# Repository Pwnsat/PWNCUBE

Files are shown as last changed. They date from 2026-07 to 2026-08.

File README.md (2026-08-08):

# PWNCUBE - The Vulnerable Satellite Hacking Platform for Learning Through Research

**A hardware-based CubeSat platform for aerospace cybersecurity research and training**, developed by PWNSAT in partnership with [ElectronicCats](https://github.com/ElectronicCats). PWNCUBE is a satellite design and vulnerability set onto real dual-core flight-computer hardware (Rockchip RV1106 — Cortex-A7 Linux + RISC-V RT-Thread), demonstrating that the same class of satellite command-and-control vulnerabilities reproduces across genuinely different hardware, not just one reference board.

Full documentation, architecture diagrams, and step-by-step guides live in the **[Wiki](../../wiki)**.

## Repository layout

| Folder | Contents |
|---|---|
| [`Firmware/`](Firmware/) | The complete RV1106 SDK source: dual-core boot (Cortex-A7 Linux + RISC-V RT-Thread), CCSDS Space Packet Protocol stack, radio/sensor/GPS drivers, build scripts. Clone-and-build (see [Getting Started](../../wiki/Getting-Started)). |
| [`Hardware/`](Hardware/) | KiCad schematics and PCB design files for the three physical boards (main/flight-computer, sensor, battery). |
| [`Case/`](Case/) | 3D-printable enclosure (STL + slicer project files). |

The 8 hardware-validated attack scripts (00–07, USB and real RF) live in a
companion `Attacks/` repository, published separately.

## What PWNCUBE demonstrates

Same protocol (CCSDS Space Packet Protocol), same command APIDs, same vulnerability classes as FlatSat — reproduced on real dual-core flight hardware instead of a single-MCU reference board:

- **No authentication** on any telecommand (thruster control, reset, firmware disclosure, mode changes)
- **No anti-replay protection** — a captured command can be resent verbatim and re-executed
- **A ground-station "auth" handshake** trivially forgeable with a static, hardcoded XOR key
- **A GPS subsystem** (real u-blox NEO-6M receiver) that trusts any injected fix with zero plausibility or rate-of-change checking
- **Plaintext telemetry by default** — no encryption on the downlink at all, unlike FlatSat's static-key AES-128
- **A memory-safety bug** (integer underflow in message reassembly) that crashes the flight computer's real-time core with a single malformed packet, permanently killing the internal command channel until a physical power-cycle

See the **[Attack Vectors](../../wiki/Attack-Vectors)** wiki page for the full walkthrough of all 8 attacks, with real hardware output for each.

## Quick start

```bash
git clone <this-repo-url> PWNCUBE-FIRMWARE
cd PWNCUBE-FIRMWARE/Firmware
# extract toolchain.tar.gz + rkbin.tar.gz from the v6 Release first — see below
./build.sh deps      # install host build dependencies (native Linux x86-64)
./build.sh            # produces output/images/update.img
```

On macOS, Windows, or if you'd rather not install packages on the host
directly, build inside Docker instead — see **[Getting Started](../../wiki/Getting-Started)**
for the full walkthrough (both paths), including flashing, which always
needs a real Linux x86-64 host or VM with USB passthrough regardless of how
you built.

## Note on repository size

This repository intentionally excludes two things present in the original SDK archive, both available as assets on the **[v6 Release](../../releases/tag/v6)**:

- **`toolchain/`** (ARM + RISC-V cross-compilers, ~2.6GB) — third-party, freely redistributable, just too large for a source repo.
- **`src/rkbin/`** (Rockchip's proprietary boot-stage binaries) — third-party, provided by ElectronicCats.

Everything else — kernel, U-Boot, the RT-Thread MCU firmware, all PWNSAT-authored application code — is included as source.

## Disclaimer

This project was created for educational purposes, to teach and learn aerospace cybersecurity. Neither PWNSAT nor Electronic Cats are responsible for how the knowledge, code, or tools hosted in this repository are used. Use only against hardware, firmware, or signal sources you own or are explicitly authorized to test.

## License

Firmware source: see [`Firmware/README.md`](Firmware/README.md#license) for the per-component breakdown (this SDK integrates code under several different open-source licenses). Attack scripts and this repository's own documentation: MIT unless noted otherwise.

## Related projects

- **[FlatSat](https://github.com/Pwnsat/FlatSat)** — the original single-MCU (RP2040) satellite security training platform this project ports from.
- **PWNSAT-C3** — the shared ground-station dashboard used to operate both FlatSat and PWNCUBE (separate repository).

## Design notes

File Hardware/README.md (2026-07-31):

# PWNCUBE hardware — KiCad schematics and PCB design files

Design files for the three physical boards that make up a PWNCUBE (see
[Hardware Anatomy](https://github.com/Pwnsat/PWNCUBE/wiki/Hardware-Anatomy)
in the wiki for how they connect and what runs on each).

| Folder | Board | Contains |
|---|---|---|
| `PWNSAT/` | Main / flight-computer board | RV1106 SoC, radios, USB selector, power supply |
| `Sensor_Board/` | Sensor board | BME280 + ICM-42670, sensor connectors |
| `Battery_Board/` | Power/battery board | Battery holder, USB, battery connector |

Each board folder is a self-contained KiCad project: `.kicad_pro` (project),
`.kicad_sch` (schematic sheets), `.kicad_pcb` (PCB layout), `.pretty/`
(custom footprint library), and `3D/` (3D models for parts used in that
board's layout, `.step`/`.stp`/`.igs`).

## Opening a project

Requires [KiCad](https://www.kicad.org/) (developed against KiCad 7/8).
Open the `.kicad_pro` file in each board's folder — schematic and PCB editors
are reachable from there.

## Generating manufacturing files (gerbers)

`electroniccats_pcb.kibot.yaml` and `electroniccats_sch.kibot.yaml` are
[KiBot](https://github.com/INTI-CMNB/KiBot) configs for JLCPCB-compatible
output (gerbers + drill files, schematic PDF). With KiBot installed:

```bash
kibot -c electroniccats_pcb.kibot.yaml -e <board>/<board>.kicad_sch -b <board>/<board>.kicad_pcb
```

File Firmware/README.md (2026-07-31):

# RV1106 SDK — CubeSat flight-computer firmware

SDK for the Rockchip RV1106, CubeSat flight computer. **Dual-core** boot:
Cortex-A7 (Linux, mission) + RISC-V SCR1 "HPMCU" coprocessor (RT-Thread,
deterministic hardware control). The MCU owns the **2x SX1262 radios (SPI)**,
the **BME280 + ICM-42670 sensors (I²C0)**, and a real **u-blox NEO-6M GPS
receiver (UART0)** — exposing all of it to Linux over rpmsg (`radio_test` /
`sensor_test`). Based on the Luckfox Pico SDK V1.4.

Board: RV1106 SDK (SPI NAND, 256 MB)

> ⚠️ **This is a source repository, not a self-contained SDK archive.** Two
> large, third-party pieces are excluded — see
> **[Getting Started](docs/getting-started.en.md)** for what to download and
> where to place it before your first build.

## Components

| Component | Version |
|---|---|
| Kernel | Linux 5.10.160 |
| U-Boot | 2017.09 + rkbin |
| MCU firmware | RT-Thread (Syntacore SCR1, rv32imc) — `rtthread.bin` |
| Busybox | 1.27.2 |
| Toolchain ARM | GCC 8.3, uClibc, ARMv7-a hard-float (not included, see above) |
| Toolchain RISC-V | xpack riscv-none-embed-gcc 10.2.0 (not included, see above) |
| Rootfs | ext4 (also supports squashfs, ubifs, initramfs) |

## Requirements

Install all host dependencies with **one command**:

```bash
./build.sh deps        # = ./scripts/install-deps.sh (apt, Debian/Ubuntu)
```

Installs: `git make gcc g++ bc cpio rsync fakeroot bison flex libssl-dev
device-tree-compiler scons gawk texinfo cmake unzip gperf autoconf
libncurses5-dev pkg-config python3` (the ARM and RISC-V toolchains are a
separate download, see **[Getting Started](docs/getting-started.en.md)**).
`scons` is required for the MCU firmware (RT-Thread) — without it, that
component is silently skipped.

## Usage

```bash
# Set up the toolchain (once per terminal)
source scripts/00-setup-toolchain.sh

# Full build from scratch
./build.sh

# Full rebuild (clean + build)
./build.sh rebuild

# Help
./build.sh help

# Individual components
./build.sh uboot     # U-Boot only (embeds the MCU's rtthread.bin)
./build.sh kernel    # Kernel only
./build.sh mcu       # RISC-V MCU firmware only (rtthread.bin)
./build.sh rootfs    # Rootfs + packages only
./build.sh pack      # Package update.img only
./build.sh flash     # Flash to the device (sudo)
./build.sh clean     # Clean everything
./build.sh info      # Show configuration

# Package management
./pkg/pkg.sh list                    # Available packages
./pkg/pkg.sh enable dropbear         # Enable SSH
./pkg/pkg.sh build-all               # Build enabled packages
./pkg/pkg.sh menuconfig              # whiptail TUI
```

## Updating the firmware (step by step)

Updating is **build → package → load**. You can rebuild a single component
or everything, but the image you flash is always `update.img`.

### 1. Build each component (individually)

```bash
source scripts/00-setup-toolchain.sh   # once per terminal

./build.sh mcu       # MCU RISC-V firmware (rtthread.bin)
./build.sh uboot     # U-Boot (idblock, uboot, trust)
./build.sh kernel    # kernel + DTB + boot.img
./build.sh rootfs    # busybox + packages + rootfs
```

> ⚠️ **Order matters:** `uboot` **embeds** `rtthread.bin` inside
> `uboot.img`/`trust.img`. If you touch the MCU, **always** run
> `./build.sh mcu` **before** `./build.sh uboot`, or the board will boot with
> the old MCU firmware. Packages are built after the kernel; if you edit a
> package, rebuild it with `./pkg/pkg.sh build-all` before `rootfs`.

### 2. Build everything together

```bash
./build.sh            # correct order: mcu → uboot → kernel → packages → rootfs → pack
./build.sh rebuild    # same, with a clean first
```

### 3. Assemble the final image

```bash
./build.sh pack       # combines every output/images/*.img into update.img
```

`./build.sh` (full) already does this step at the end. You only need a bare
`pack` if you rebuilt a single component and want to re-package without a
full rebuild.

### 4. Enter bootloader mode (maskrom) and flash

On the board:

1. **Hold the `BOOT` button.**
2. Without releasing `BOOT`, **press and release `RST` (reset)**.
3. Keep holding `BOOT` for ~**5 s** until the host detects the device in
   maskrom mode, then release `BOOT`.

**How do I know it's in maskrom?** Check from the host:

```bash
sudo tools/upgrade_tool LD        # lists connected Rockchip devices
# Maskrom OK →  DevNo=1  Vid=0x2207,Pid=0x350a,...  Mode=Maskrom

lsusb | grep 2207                 # alternative: Rockchip = VID 0x2207
# ID 2207:350a  → maskrom;  ID 2207:110a  → already in Loader mode (U-Boot)
```

If `LD` lists nothing or `lsusb` shows no `2207:xxxx`, the board did **not**
enter maskrom: repeat the button sequence. `Mode=Maskrom` (or `Loader`) is
the only reliable confirmation before flashing.

With the board already in Linux, you can enter without touching buttons via
`reboot loader` from the serial shell.

Then, from the host:

```bash
./build.sh flash                              # = upgrade_tool UF output/images/update.img (sudo)
# or directly:
sudo tools/upgrade_tool UF output/images/update.img
```

> ⚠️ Always use **`UF`** (full image). `DI -b` responds "ok" but **does not
> write** on this SPI-NAND. If you flashed using the recovery button,
> **release it as soon as flashing starts** or the subsequent reboot will be
> silent.

Register-level boot detail, dual A7+MCU boot, and every gotcha found along
the way:
[`docs/migration/implementation/90-mcu-config-replication.md`](docs/migration/implementation/90-mcu-config-replication.md)
and
[`docs/migration/implementation/80-dual-boot.md`](docs/migration/implementation/80-dual-boot.md).

## Outputs

After `./build.sh`, in `output/images/`:

| File | Description |
|---|---|
| `idblock.img` | Boot loader (DDR init + SPL) |
| `download.bin` | Raw loader for Rockchip tools |
| `uboot.img` | U-Boot proper |
| `trust.img` | OP-TEE + HPMCU |
| `boot.img` | Kernel FIT (Image + DTB) |
| `env.img` | U-Boot environment (partitions + bootargs) |
| `rootfs_base.img` | Rootfs |
| `update.img` | Full flashable image |

## Partition layout (SPI NAND — 256 MB)

```
256K(env), 512K@256K(idblock), 256K@768K(uboot), 32M@1024K(boot), -(rootfs)
```

## Documentation

Full documentation lives in `docs/`. Start with the index
[`docs/README.md`](docs/README.md).

- **Architecture** — `docs/architecture/`: overview, rpmsg IPC, and
  peripheral ownership (what the RISC-V MCU owns vs. Linux).
- **Build** — `docs/build/`: `toolchain`, `uboot`, `kernel`, `rootfs`,
  `packaging`, `pkg-system`.
- **Peripherals** (owned by the MCU, handled over rpmsg) — `docs/peripherals/`:
  `sx1262-radio`, `bme280`, `icm42670`, `gps-neo6m` (real GPS, UART0 — driver
  in `src/mcu/rt-thread/bsp/rockchip/rv1106-mcu/applications/gps_nmea.c`/`.h`,
  queried from Linux with `radio_test gps_status`).
- **Security** — `docs/security/exploitation-guide.md`.
- **RISC-V migration / MCU firmware** (bring-up log, dual boot, register-level
  configuration) — `docs/migration/`.

## License

This SDK integrates code under several different open-source licenses, by
component:

| Component | License |
|---|---|
| PWNSAT-authored application code (`applications/`, `radio-client/`, `pwnsat-console/`, attack-facing tooling) | MIT |
| Linux kernel (`src/kernel/`) | GPL-2.0 |
| U-Boot (`src/u-boot/`) | GPL-2.0 |
| Busybox (`src/busybox/`) | GPL-2.0 |
| Toolchains (not in this repo's tree — see the [v6 Release](../../../releases/tag/v6)) | GPL-3.0 / LGPL-2.1 |
| `rkbin` (not in this repo's tree — see the [v6 Release](../../../releases/tag/v6)) | Proprietary, Rockchip |

Known limitation, documented rather than hidden: **the sensor telemetry
frame's pressure and altitude fields can overflow their 16-bit fixed-point
encoding.** Pressure (hPa × 100) exceeds `int16_t` range for *any* real
atmospheric pressure — this field wraps around unconditionally, on every
board, regardless of location. Altitude (derived from pressure via the
hypsometric formula, × 100) overflows whenever the true altitude relative
to the 1013.25hPa sea-level reference exceeds roughly ±327m, which it will
on most real boards/locations. Both are tracked as a known issue, not yet
fixed (see the inline comments at `telemetry_spp_pack_frame()` in
`src/mcu/rt-thread/bsp/rockchip/rv1106-mcu/applications/command_service.c`).
See `docs/security/exploitation-guide.en.md` for the full, deliberately
reintroduced vulnerability catalog this platform demonstrates (a separate
concern from this encoding bug).

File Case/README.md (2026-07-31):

# PWNCUBE 3D-printable case

| File | Purpose |
|---|---|
| `Base-Body_X2.3mf` | Base plate |
| `Wall-Body_X2.3mf` | Enclosure wall |
| `SingleWall-Body_X2.3mf` | Single-wall variant |
| `Poste-Body_X1.3mf` | Standoff post |
| `5_SensorBoard_x3.stl` | Sensor board mount |

`.3mf` files are slicer project files (Bambu Studio / PrusaSlicer-compatible); `.stl` is a plain mesh importable into any slicer.

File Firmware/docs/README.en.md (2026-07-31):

# PwnCube SDK — Documentation

CubeSat target on the **Rockchip RV1106** (Cortex-A7 + SCR1 RISC-V). Start with the
architecture, then build, then the per-device and security docs.

Docs are **bilingual (EN/ES)**. Each topic is `name.en.md` + `name.es.md` with `name.md` a
symlink to the active language. Switch with `./docs/switch.sh en|es` (or no argument to
toggle).

## Start here
- [`getting-started.md`](getting-started.md) — **first time?** from zero: install dependencies, clone, build the image, and flash the board

## Architecture
- [`architecture/overview.md`](architecture/overview.md) — the two cores, roles, boot, mission
- [`architecture/ipc-rpmsg.md`](architecture/ipc-rpmsg.md) — Linux↔MCU rpmsg services & endpoints
- [`architecture/peripheral-ownership.md`](architecture/peripheral-ownership.md) — which peripherals the MCU owns, how, the pin map

## Build
- [`build/toolchain.md`](build/toolchain.md) · [`build/uboot.md`](build/uboot.md) · [`build/kernel.md`](build/kernel.md) · [`build/rootfs.md`](build/rootfs.md)
- [`build/packaging.md`](build/packaging.md) — image assembly & flashing · [`build/pkg-system.md`](build/pkg-system.md) — the `pkg/` package system

## Peripherals (MCU-owned, driven over rpmsg)
- [`peripherals/sx1262-radio.md`](peripherals/sx1262-radio.md) — dual SX1262 LoRa
- [`peripherals/bme280.md`](peripherals/bme280.md) — temperature / pressure / humidity
- [`peripherals/icm42670.md`](peripherals/icm42670.md) — 6-axis IMU
- [`peripherals/gps-neo6m.md`](peripherals/gps-neo6m.md) — real u-blox NEO-6M GPS receiver, UART0

## Security
- [`security/exploitation-guide.md`](security/exploitation-guide.md) — CCSDS telecommand attack surface, step by step

## Migration (record)
How the MCU came to own the peripherals — design decisions and on-board bring-up:
- [`migration/README.md`](migration/README.md) — index of the migration series

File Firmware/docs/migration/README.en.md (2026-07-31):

# RISC-V Migration — Documentation

> **Bilingual (EN/ES).** Every document exists as `*.en.md` and `*.es.md`; the
> `*.md` link points to the active language. Switch with `./docs/switch.sh en|es`
> (or no argument to toggle). Current active language: **Spanish** (`.md` → `.es.md`).

Design **and implementation** of migrating the CubeSat flight-computer drivers
from Linux (Cortex-A7) to the **Syntacore SCR1** RISC-V coprocessor ("HPMCU",
RT-Thread), over rpmsg IPC. Covers the study of the project and of the Luckfox
SDK as a reference, the per-driver migration design, and the on-board verified
implementation.

> **This is the historical migration series. The migration is COMPLETE and
> running on hardware.** For the current-state architecture see
> [`../architecture/overview.md`](../architecture/overview.md),
> [`../architecture/ipc-rpmsg.md`](../architecture/ipc-rpmsg.md) and
> [`../architecture/peripheral-ownership.md`](../architecture/peripheral-ownership.md).

**Status:** dual boot A7+MCU **WORKING**. The MCU owns both SX1262 radios (SPI)
and both I²C0 sensors, exposed to Linux over five rpmsg endpoints —
**PingEcho** (`rpmsg-ap3-ch0`, 0x4004), **RadioService** (`rpmsg-radio`,
0x4005), **SensorService** (`rpmsg-sensor`, 0x4006), **TelemetryService**
(`rpmsg-telemetry`, 0x4007) and **CommandService** (`rpmsg-command`, 0x4008).
All **validated on hardware**; the services coexist on the same poll thread.
Linux drives them via `radio_test` / `sensor_test`.

## Project separation

| Project | Location | Role |
|---|---|---|
| **CubeSat** | this repository | Flight-computer firmware. This is what is developed. |
| **Luckfox SDK** | external reference (outside this repo) | **Technical reference only** for the RV1106. Never modified. |

Citations `sysdrv/...`, `project/...` → **Luckfox SDK**. Citations `src/...`,
`dts/...`, `pkg/...` → **this CubeSat repo**.

## Documentation structure

### `reference/` — Luckfox SDK study (technical reference)
| # | Document | Content |
|---|---|---|
| 10 | [`luckfox-riscv-boot`](reference/10-luckfox-riscv-boot.md) | How Luckfox builds, boots, loads and memory-maps the RISC-V firmware (HPMCU / RT-Thread). |
| 20 | [`luckfox-ipc`](reference/20-luckfox-ipc.md) | The real ARM↔RISC-V IPC implementation: RPMsg-Lite, Mailbox, shared memory, vrings, interrupts. |

### `design/` — Migration design
| # | Document | Content |
|---|---|---|
| 30 | [`cubesat-drivers`](design/30-cubesat-drivers.md) | Inventory of the Linux drivers: portable logic vs. Linux *glue*, buses, GPIO. |
| 40 | [`migration-design`](design/40-migration-design.md) | Per-driver migration design and target Linux↔RISC-V architecture. |
| 50 | [`ipc-protocol-roadmap`](design/50-ipc-protocol-roadmap.md) | Versioned IPC protocol, services, CCSDS and the implementation order. |

### `implementation/` — Implementation and on-board validation
| # | Document | Content |
|---|---|---|
| 60 | [`ipc-bringup`](implementation/60-ipc-bringup.md) | IPC transport status: done/verified vs. pending, memory map and co-design. |
| 70 | [`mailbox-loopback-test`](implementation/70-mailbox-loopback-test.md) | Mailbox loopback test: B2A works, A2B unreadable by the MCU, DDR shared-memory coherent. |
| 80 | [`dual-boot`](implementation/80-dual-boot.md) | **Dual boot WORKING**: definitive memory map, the 5-bug chain and their resolutions, correct flashing (UF, never `DI -b`), marker diagnostics. |
| 90 | [`mcu-config-replication`](implementation/90-mcu-config-replication.md) | **DEFINITIVE GUIDE** to MCU configuration (register by register), memory rules, BSP, rpmsg transport, the peripheral + shared-driver patterns, **RadioService** (§7bis) and **SensorService** (§7ter), endpoint routing, build/flash and the replication checklist. |

**Suggested reading path:** start with 90 (replication guide) if you'll touch
the MCU; 80 to understand dual boot; 10/20 as SoC reference; 40/50 for the design.

## Executive summary — constraints that shaped the design

Four facts verified in the code, the foundation of the migration (detail in 10/20):

1. **The RISC-V is a Syntacore SCR1, `rv32imc`/`ilp32`.** Toolchain
   `riscv-none-embed-gcc 10.2.0`. The artifact is `rtthread.bin`, loaded at
   `0x40000`.
2. **Very tight memory.** The MCU RAM is **240 KB** (`link.lds`
   `ORIGIN=0x40000, LENGTH=0x3c000`); the HPMCU shared SRAM is **8 KB**
   (`hpmcu_sram@0xff6fe000`). Every migrated driver must fit this budget.
3. **SPI/I²C on the MCU are HAL-only, not wired by the BSP.** They are driven
   with **direct HAL** (PIO/POLL), without the RT-Thread driver framework, and
   the bus is ceded from Linux in the device tree. *(Done: buses ceded, drivers
   MCU-native.)*
4. **The IPC stack existed but was NOT wired for the RV1106** (rpmsg driver
   match, porting, device tree). *(Done: rpmsg transport working via vring
   polling + blind mailbox ACK.)*

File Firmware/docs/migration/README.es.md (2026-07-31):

# Migración a RISC-V — Documentación

> **Bilingüe (EN/ES).** Cada documento existe como `*.en.md` y `*.es.md`; el
> enlace `*.md` apunta al idioma activo. Cambia con `./docs/switch.sh en|es`
> (o sin argumento para alternar). Idioma activo actual: **Español**.

Diseño **e implementación** de la migración de los drivers de la computadora de
vuelo CubeSat desde Linux (Cortex-A7) al coprocesador RISC-V **Syntacore SCR1**
("HPMCU", RT-Thread), sobre IPC rpmsg. Cubre el estudio del proyecto y del SDK
Luckfox como referencia, el diseño de la migración por driver, y la
implementación verificada en placa.

> **Esta es la serie histórica de la migración. La migración está COMPLETA y
> corriendo en hardware.** Para la arquitectura del estado actual ver
> [`../architecture/overview.md`](../architecture/overview.md),
> [`../architecture/ipc-rpmsg.md`](../architecture/ipc-rpmsg.md) y
> [`../architecture/peripheral-ownership.md`](../architecture/peripheral-ownership.md).

**Estado:** arranque dual A7+MCU **FUNCIONANDO**. El MCU posee ambas radios
SX1262 (SPI) y ambos sensores I²C0, expuestos a Linux por cinco endpoints
rpmsg — **PingEcho** (`rpmsg-ap3-ch0`, 0x4004), **RadioService**
(`rpmsg-radio`, 0x4005), **SensorService** (`rpmsg-sensor`, 0x4006),
**TelemetryService** (`rpmsg-telemetry`, 0x4007) y **CommandService**
(`rpmsg-command`, 0x4008). Todos **validados en placa**; los servicios
coexisten en el mismo hilo de poll. Linux los maneja vía `radio_test` /
`sensor_test`.

## Separación de proyectos

| Proyecto | Ubicación | Rol |
|---|---|-----|
| **CubeSat** | este repositorio | Firmware de la computadora de vuelo. Es lo que se desarrolla. |
| **SDK Luckfox** | referencia externa (fuera de este repo) | **Solo referencia técnica** del RV1106. No se modifica. |

Citas `sysdrv/...`, `project/...` → **SDK Luckfox**. Citas `src/...`, `dts/...`,
`pkg/...` → **este repo CubeSat**.

## Estructura de la documentación

### `reference/` — Estudio del SDK Luckfox (referencia técnica)
| # | Documento | Contenido |
|---|---|---|
| 10 | [`luckfox-riscv-boot`](reference/10-luckfox-riscv-boot.md) | Cómo Luckfox compila, arranca, carga y mapea en memoria el firmware RISC-V (HPMCU / RT-Thread). |
| 20 | [`luckfox-ipc`](reference/20-luckfox-ipc.md) | Implementación real de IPC ARM↔RISC-V: RPMsg-Lite, Mailbox, memoria compartida, vrings, interrupciones. |

### `design/` — Diseño de la migración
| # | Documento | Contenido |
|---|---|---|
| 30 | [`cubesat-drivers`](design/30-cubesat-drivers.md) | Inventario de los drivers Linux: lógica portable vs. *glue* de Linux, buses, GPIO. |
| 40 | [`migration-design`](design/40-migration-design.md) | Diseño de la migración por driver y arquitectura objetivo Linux↔RISC-V. |
| 50 | [`ipc-protocol-roadmap`](design/50-ipc-protocol-roadmap.md) | Protocolo IPC versionado, servicios, CCSDS y orden de implementación. |

### `implementation/` — Implementación y validación en placa
| # | Documento | Contenido |
|---|---|---|
| 60 | [`ipc-bringup`](implementation/60-ipc-bringup.md) | Estado del transporte IPC: hecho/verificado vs. pendiente, mapa de memoria y co-diseño. |
| 70 | [`mailbox-loopback-test`](implementation/70-mailbox-loopback-test.md) | Test de loopback del mailbox: B2A funciona, A2B ilegible por el MCU, shared-memory DDR coherente. |
| 80 | [`dual-boot`](implementation/80-dual-boot.md) | **Arranque dual FUNCIONANDO**: mapa de memoria definitivo, la cadena de 5 bugs y sus resoluciones, flasheo correcto (UF, nunca `DI -b`), diagnóstico por marcadores. |
| 90 | [`mcu-config-replication`](implementation/90-mcu-config-replication.md) | **GUÍA DEFINITIVA** de configuración del MCU (registro a registro), reglas de memoria, BSP, transporte rpmsg, patrón de periféricos y driver compartido, **RadioService** (§7bis) y **SensorService** (§7ter), ruteo de endpoints, build/flash y checklist de replicación. |

**Ruta de lectura sugerida:** empieza por el 90 (guía de replicación) si vas a
tocar el MCU; el 80 para entender el arranque dual; 10/20 como referencia del
SoC; 40/50 para el diseño.

## Resumen ejecutivo — restricciones que condicionaron el diseño

Cuatro hechos verificados en el código, base de la migración (detalle en 10/20):

1. **El RISC-V es un Syntacore SCR1, `rv32imc`/`ilp32`.** Toolchain
   `riscv-none-embed-gcc 10.2.0`. El artefacto es `rtthread.bin`, cargado en
   `0x40000`.
2. **Memoria muy ajustada.** La RAM del MCU son **240 KB** (`link.lds`
   `ORIGIN=0x40000, LENGTH=0x3c000`); la SRAM compartida del HPMCU son **8 KB**
   (`hpmcu_sram@0xff6fe000`). Todo driver migrado cabe en este presupuesto.
3. **SPI/I²C en el MCU son solo HAL, no cableados por el BSP.** Se manejan con
   **HAL directo** (PIO/POLL), sin el framework de drivers de RT-Thread, y se
   cede el bus desde Linux en el device tree. *(Hecho: buses cedidos, drivers
   MCU-native.)*
4. **El stack de IPC existía pero NO estaba cableado para el RV1106** (match del
   driver rpmsg, porting, device tree). *(Hecho: transporte rpmsg funcionando
   por poll de vrings + ACK ciego del mailbox.)*

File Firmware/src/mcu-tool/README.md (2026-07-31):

# mcutool — hot-load the RISC-V MCU from Linux

`mcutool` resets, loads, and releases the RV1106 SCR1 RISC-V MCU **from Linux
userspace** (`/dev/mem`), using the exact register sequence our U-Boot SPL uses
to release `mcu0` (`src/u-boot/arch/arm/mach-rockchip/rv1106/rv1106.c:557`).

Purpose: iterate MCU firmware **without a full reflash** (build → uboot → pack →
`reboot loader` → `upgrade_tool UF`), and recover a wedged MCU without rebooting
the whole board. Adapted from [luyi1888/rv1106-mcu](https://github.com/luyi1888/rv1106-mcu) (GPL-3.0).

## Build / install

Enabled as the `mcu-tool` package (`PKG_ENABLE_mcu-tool=y`), cross-compiled and
installed to `/usr/bin/mcutool`. Needs `CONFIG_DEVMEM=y` (added to the kernel
defconfig) and root on the device.

## Usage (on the device)

```
mcutool execute FILE [ADDR]   # load firmware + run (ADDR default 0x40000, our DDR)
mcutool load    FILE [ADDR]   # load firmware only (stays in reset)
mcutool run                   # release (start) the MCU
mcutool stop                  # reset (halt) the MCU
```

Get the firmware onto the device first (the image is **not** on the rootfs — it
is normally embedded in U-Boot):

```sh
# host: build the MCU, then copy the raw binary to the device
scp src/mcu/output/image/rtthread.bin root@<device>:/tmp/
# device:
mcutool execute /tmp/rtthread.bin      # loads to 0x40000 and starts it
```

## Caveat: rpmsg after a hot-reload (dual-boot)

The MCU is normally released by the SPL with a **live rpmsg link** (virtio0 +
reserved DDR + `/dev/rpmsg*` bound to `rpmsg_chrdev`). Resetting and reloading
tears the MCU side down; the new firmware re-announces its endpoints, but the
Linux char bindings are stale. After `mcutool execute`, re-bind them (same
commands as `rootfs/skeleton/etc/init.d/rcS`):

```sh
bind() { echo rpmsg_chrdev > /sys/bus/rpmsg/devices/$1/driver_override; \
         echo $1 > /sys/bus/rpmsg/drivers/rpmsg_chrdev/bind; }
bind virtio0.rpmsg-radio.-1.16389
bind virtio0.rpmsg-sensor.-1.16390
bind virtio0.rpmsg-telemetry.-1.16391
bind virtio0.rpmsg-command.-1.16392
```

If the virtio/vring state has desynced past recovery, reboot. This tool is a
**dev aid**; for firmware that owns rpmsg it is best-effort. It is flawless for
firmware that does not depend on a live rpmsg link (bring-up, standalone tests).

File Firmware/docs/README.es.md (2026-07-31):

# SDK PwnCube — Documentación

Target CubeSat sobre el **Rockchip RV1106** (Cortex-A7 + SCR1 RISC-V). Empieza por la
arquitectura, luego build, y después los docs por dispositivo y de seguridad.

Los docs son **bilingües (EN/ES)**. Cada tema es `name.en.md` + `name.es.md` con `name.md` un
symlink al idioma activo. Cambia con `./docs/switch.sh en|es` (o sin argumento para alternar).

## Empieza aquí
- [`getting-started.md`](getting-started.md) — **¿primera vez?** desde cero: instalar dependencias, clonar, compilar la imagen y flashear la placa

## Arquitectura
- [`architecture/overview.md`](architecture/overview.md) — los dos núcleos, roles, boot, misión
- [`architecture/ipc-rpmsg.md`](architecture/ipc-rpmsg.md) — servicios y endpoints rpmsg Linux↔MCU
- [`architecture/peripheral-ownership.md`](architecture/peripheral-ownership.md) — qué periféricos posee el MCU, cómo, el mapa de pines

## Build
- [`build/toolchain.md`](build/toolchain.md) · [`build/uboot.md`](build/uboot.md) · [`build/kernel.md`](build/kernel.md) · [`build/rootfs.md`](build/rootfs.md)
- [`build/packaging.md`](build/packaging.md) — ensamblado de imagen y flasheo · [`build/pkg-system.md`](build/pkg-system.md) — el sistema de paquetes `pkg/`

## Periféricos (los posee el MCU, manejados por rpmsg)
- [`peripherals/sx1262-radio.md`](peripherals/sx1262-radio.md) — SX1262 LoRa dual
- [`peripherals/bme280.md`](peripherals/bme280.md) — temperatura / presión / humedad
- [`peripherals/icm42670.md`](peripherals/icm42670.md) — IMU de 6 ejes

## Seguridad
- [`security/exploitation-guide.md`](security/exploitation-guide.md) — superficie de ataque de telecomandos CCSDS, paso a paso

## Migración (registro)
Cómo el MCU llegó a poseer los periféricos — decisiones de diseño y bring-up en placa:
- [`migration/README.md`](migration/README.md) — índice de la serie de migración

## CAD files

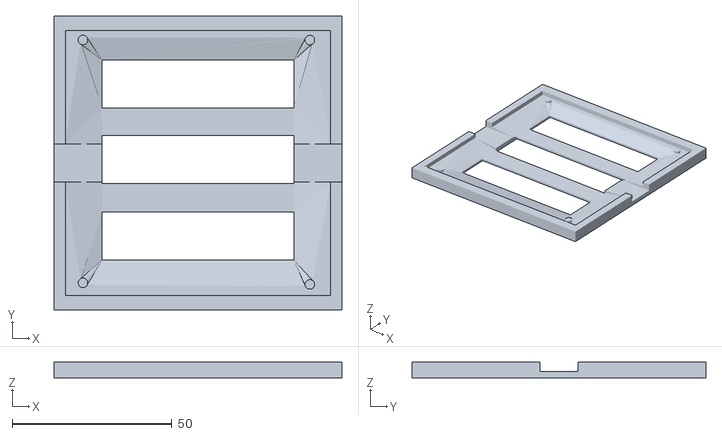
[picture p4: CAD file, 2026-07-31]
Case/5_SensorBoard_x3.stl
90.0 x 92.0 x 5.00

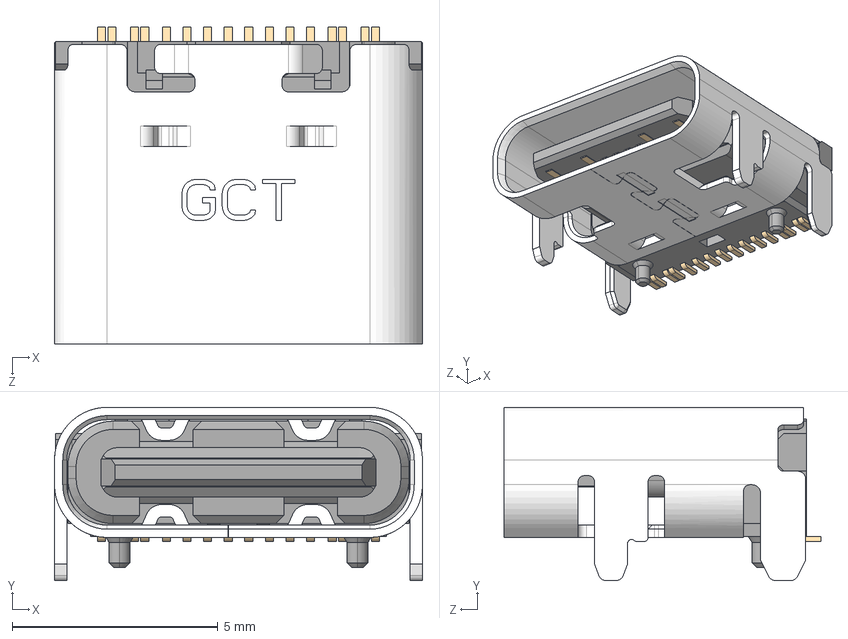
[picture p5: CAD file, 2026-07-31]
Hardware/Battery_Board/3D/USB4105-GF-A.stp
8.94 x 4.21 x 7.70 mm
HSG_默认

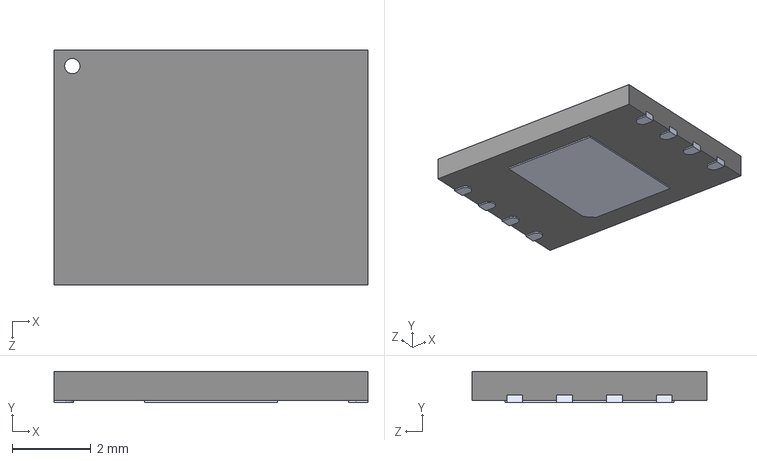
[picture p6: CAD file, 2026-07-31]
Hardware/PWNSAT/3D/W25Q01JVZEIQ.STEP
8.00 x 0.8 x 6.00 mm

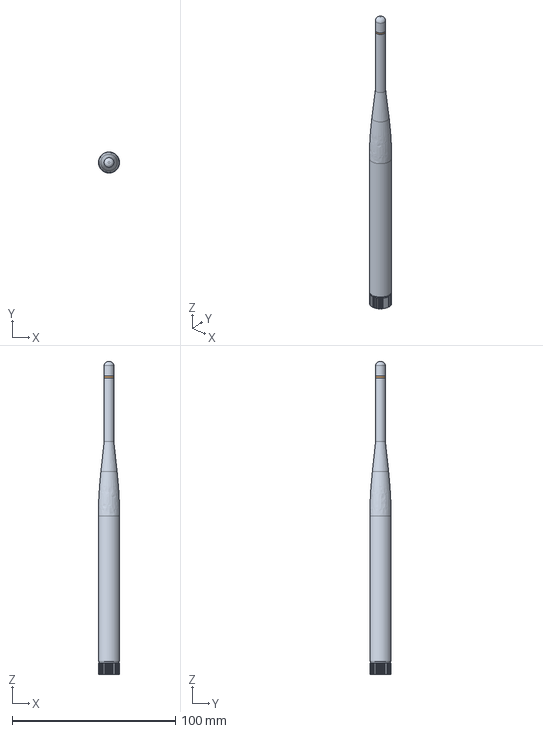
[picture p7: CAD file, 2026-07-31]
Hardware/Sensor_Board/3D/antenna_915Mhz-antenna_915Mhz.step
13.0 x 13.0 x 192.0 mm

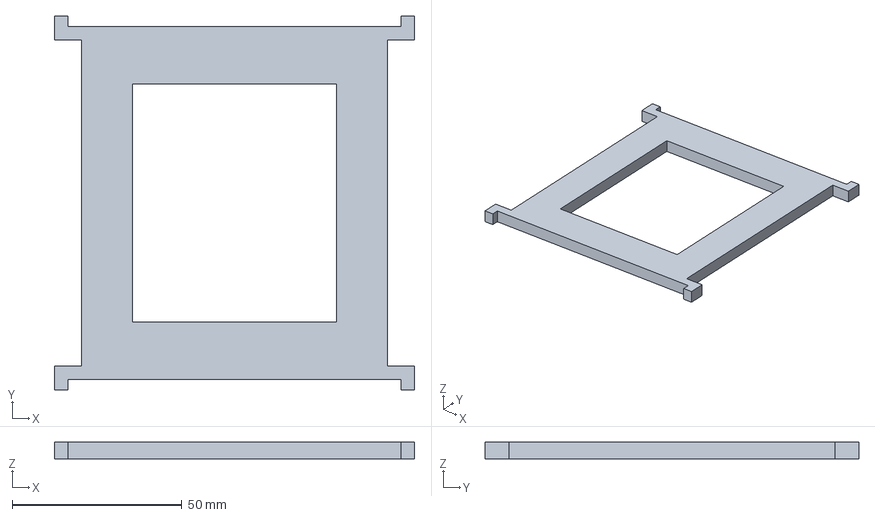
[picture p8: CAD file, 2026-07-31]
Case/Base-Body_X2.3mf
106.0 x 110.0 x 5.00 mm

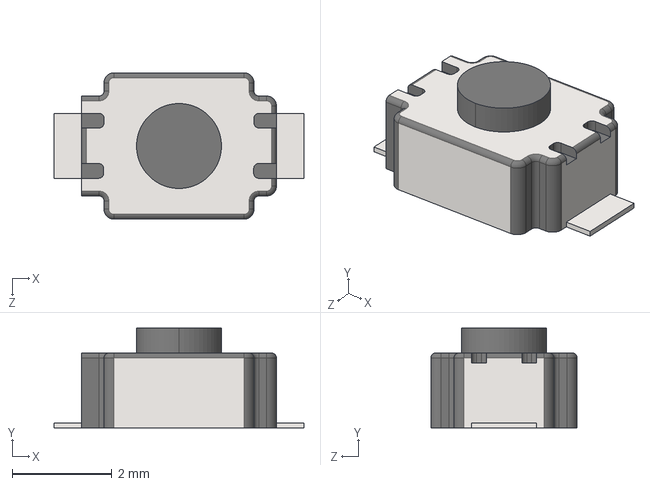
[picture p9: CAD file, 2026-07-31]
Hardware/Battery_Board/3D/TS-1088R-02526.STEP
5.00 x 2.00 x 2.93 mm

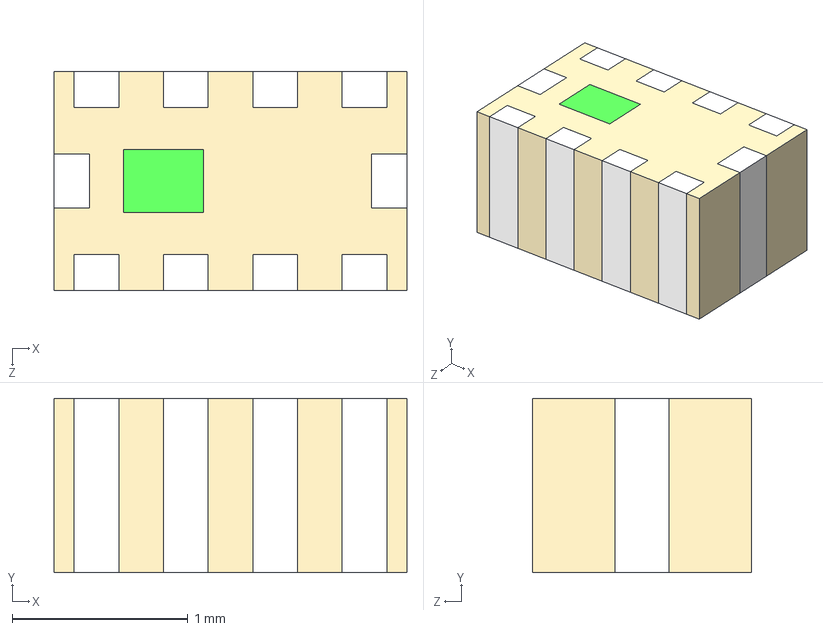
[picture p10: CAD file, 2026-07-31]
Hardware/PWNSAT/3D/0900PC15A0036E--3DModel-STEP-56544.STEP
2.01 x 0.991 x 1.24 mm

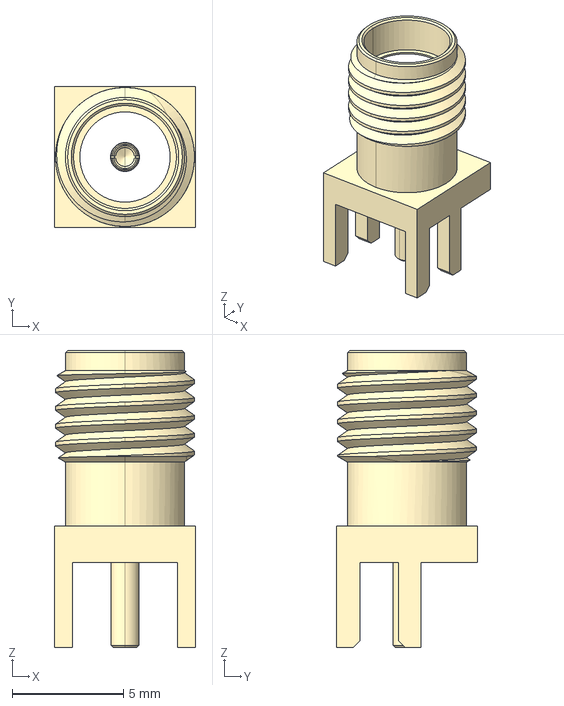
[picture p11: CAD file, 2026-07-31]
Hardware/Sensor_Board/3D/SAMTEC_SMA-J-P-H-ST-EM1.STEP
6.35 x 6.35 x 13.3 mm

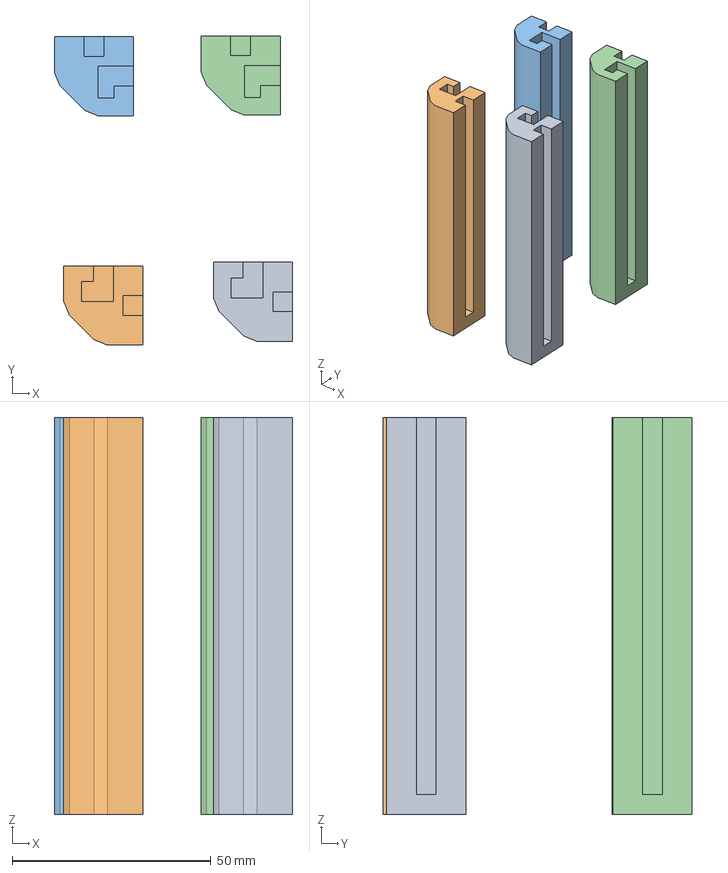
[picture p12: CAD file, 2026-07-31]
Case/Poste-Body_X1.3mf
60.1 x 77.9 x 100.0 mm

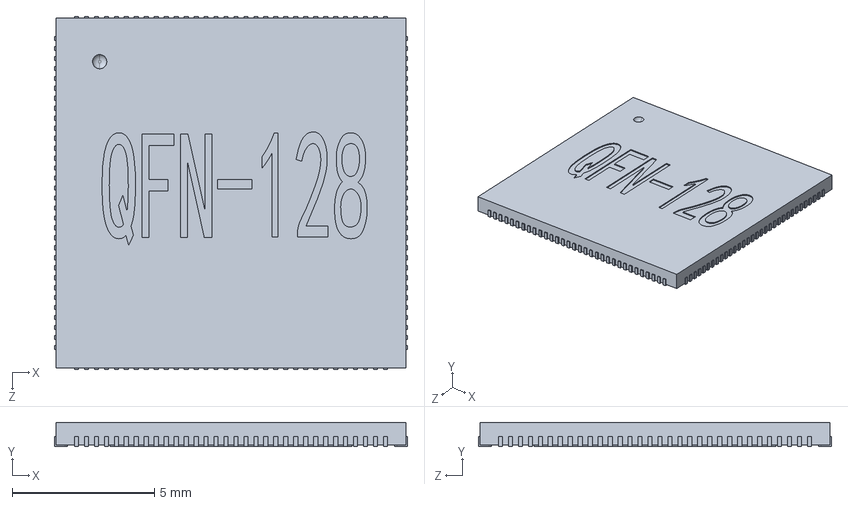
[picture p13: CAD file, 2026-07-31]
Hardware/PWNSAT/3D/User Library-qfn-128.STEP
12.4 x 0.85 x 12.4 mm

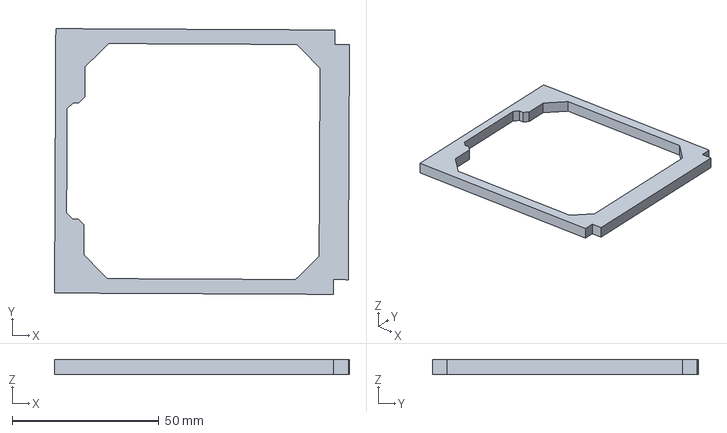
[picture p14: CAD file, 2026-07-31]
Case/SingleWall-Body_X2.3mf
100.4 x 90.5 x 5.00 mm

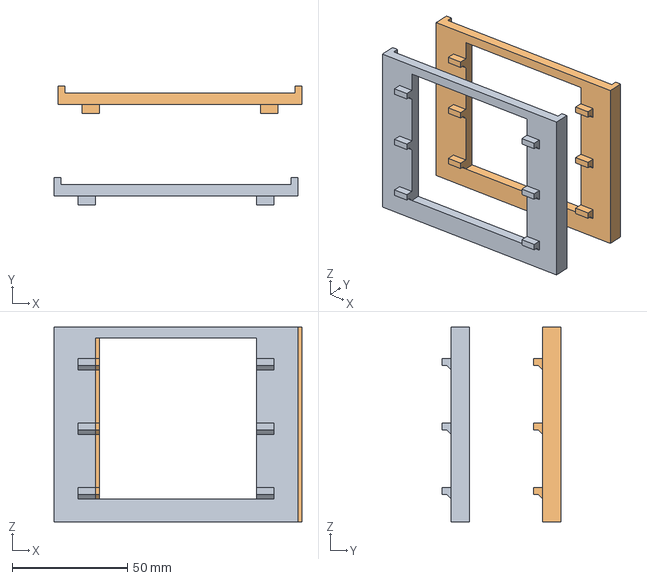
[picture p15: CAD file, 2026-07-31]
Case/Wall-Body_X2.3mf
107.7 x 51.7 x 84.7 mm

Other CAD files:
Hardware/PWNSAT/3D/1001-001-01000.igs
Hardware/PWNSAT/3D/CMUSB661022B.stp

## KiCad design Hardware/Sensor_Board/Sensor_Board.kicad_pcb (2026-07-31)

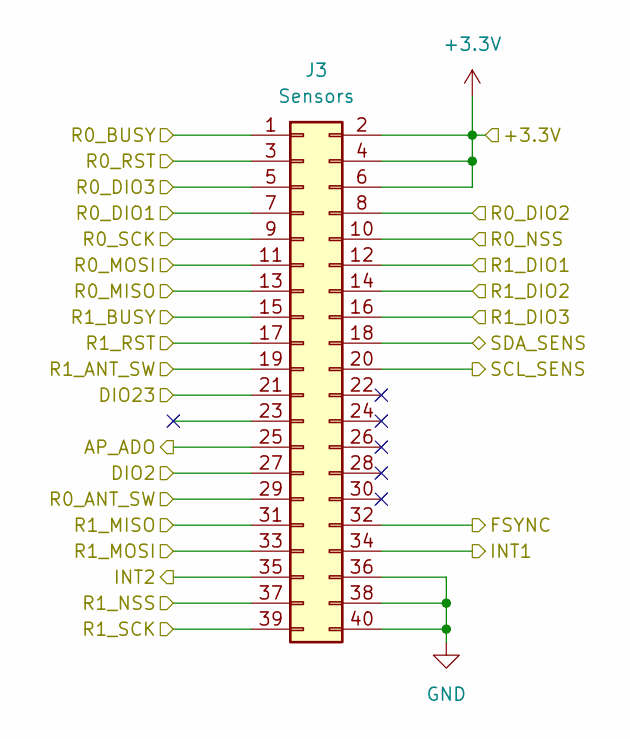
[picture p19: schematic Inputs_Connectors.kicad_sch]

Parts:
J3: Sensors; PinHeader_2x20_P2.54mm_Vertical; LCSC# C7501249

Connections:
+3.3V: J3.2, J3.4, J3.6; also elsewhere on the board
/Inputs_Connectors/AP_ADO: J3.25; also elsewhere on the board
/Inputs_Connectors/DIO2: J3.27; also elsewhere on the board
/Inputs_Connectors/DIO23: J3.21; also elsewhere on the board
/Inputs_Connectors/FSYNC: J3.32; also elsewhere on the board
/Inputs_Connectors/INT1: J3.34; also elsewhere on the board
/Inputs_Connectors/INT2: J3.35; also elsewhere on the board
/Inputs_Connectors/R0_ANT_SW: J3.29; also elsewhere on the board
/Inputs_Connectors/R0_BUSY: J3.1; also elsewhere on the board
/Inputs_Connectors/R0_DIO1: J3.7; also elsewhere on the board
/Inputs_Connectors/R0_DIO3: J3.5; also elsewhere on the board
/Inputs_Connectors/R0_MISO: J3.13; also elsewhere on the board
/Inputs_Connectors/R0_MOSI: J3.11; also elsewhere on the board
/Inputs_Connectors/R0_NSS: J3.10; also elsewhere on the board
/Inputs_Connectors/R0_RST: J3.3; also elsewhere on the board
/Inputs_Connectors/R0_SCK: J3.9; also elsewhere on the board
/Inputs_Connectors/R1_ANT_SW: J3.19; also elsewhere on the board
/Inputs_Connectors/R1_BUSY: J3.15; also elsewhere on the board
/Inputs_Connectors/R1_DIO1: J3.12; also elsewhere on the board
/Inputs_Connectors/R1_DIO3: J3.16; also elsewhere on the board
/Inputs_Connectors/R1_MISO: J3.31; also elsewhere on the board
/Inputs_Connectors/R1_MOSI: J3.33; also elsewhere on the board
/Inputs_Connectors/R1_NSS: J3.37; also elsewhere on the board
/Inputs_Connectors/R1_RST: J3.17; also elsewhere on the board
/Inputs_Connectors/R1_SCK: J3.39; also elsewhere on the board
/Inputs_Connectors/SCL_SENS: J3.20; also elsewhere on the board
/Inputs_Connectors/SDA_SENS: J3.18; also elsewhere on the board
/Sensors/R0_DIO2: J3.8; also elsewhere on the board
/Sensors/R1_DIO2: J3.14; also elsewhere on the board
GND: J3.36, J3.38, J3.40; also elsewhere on the board

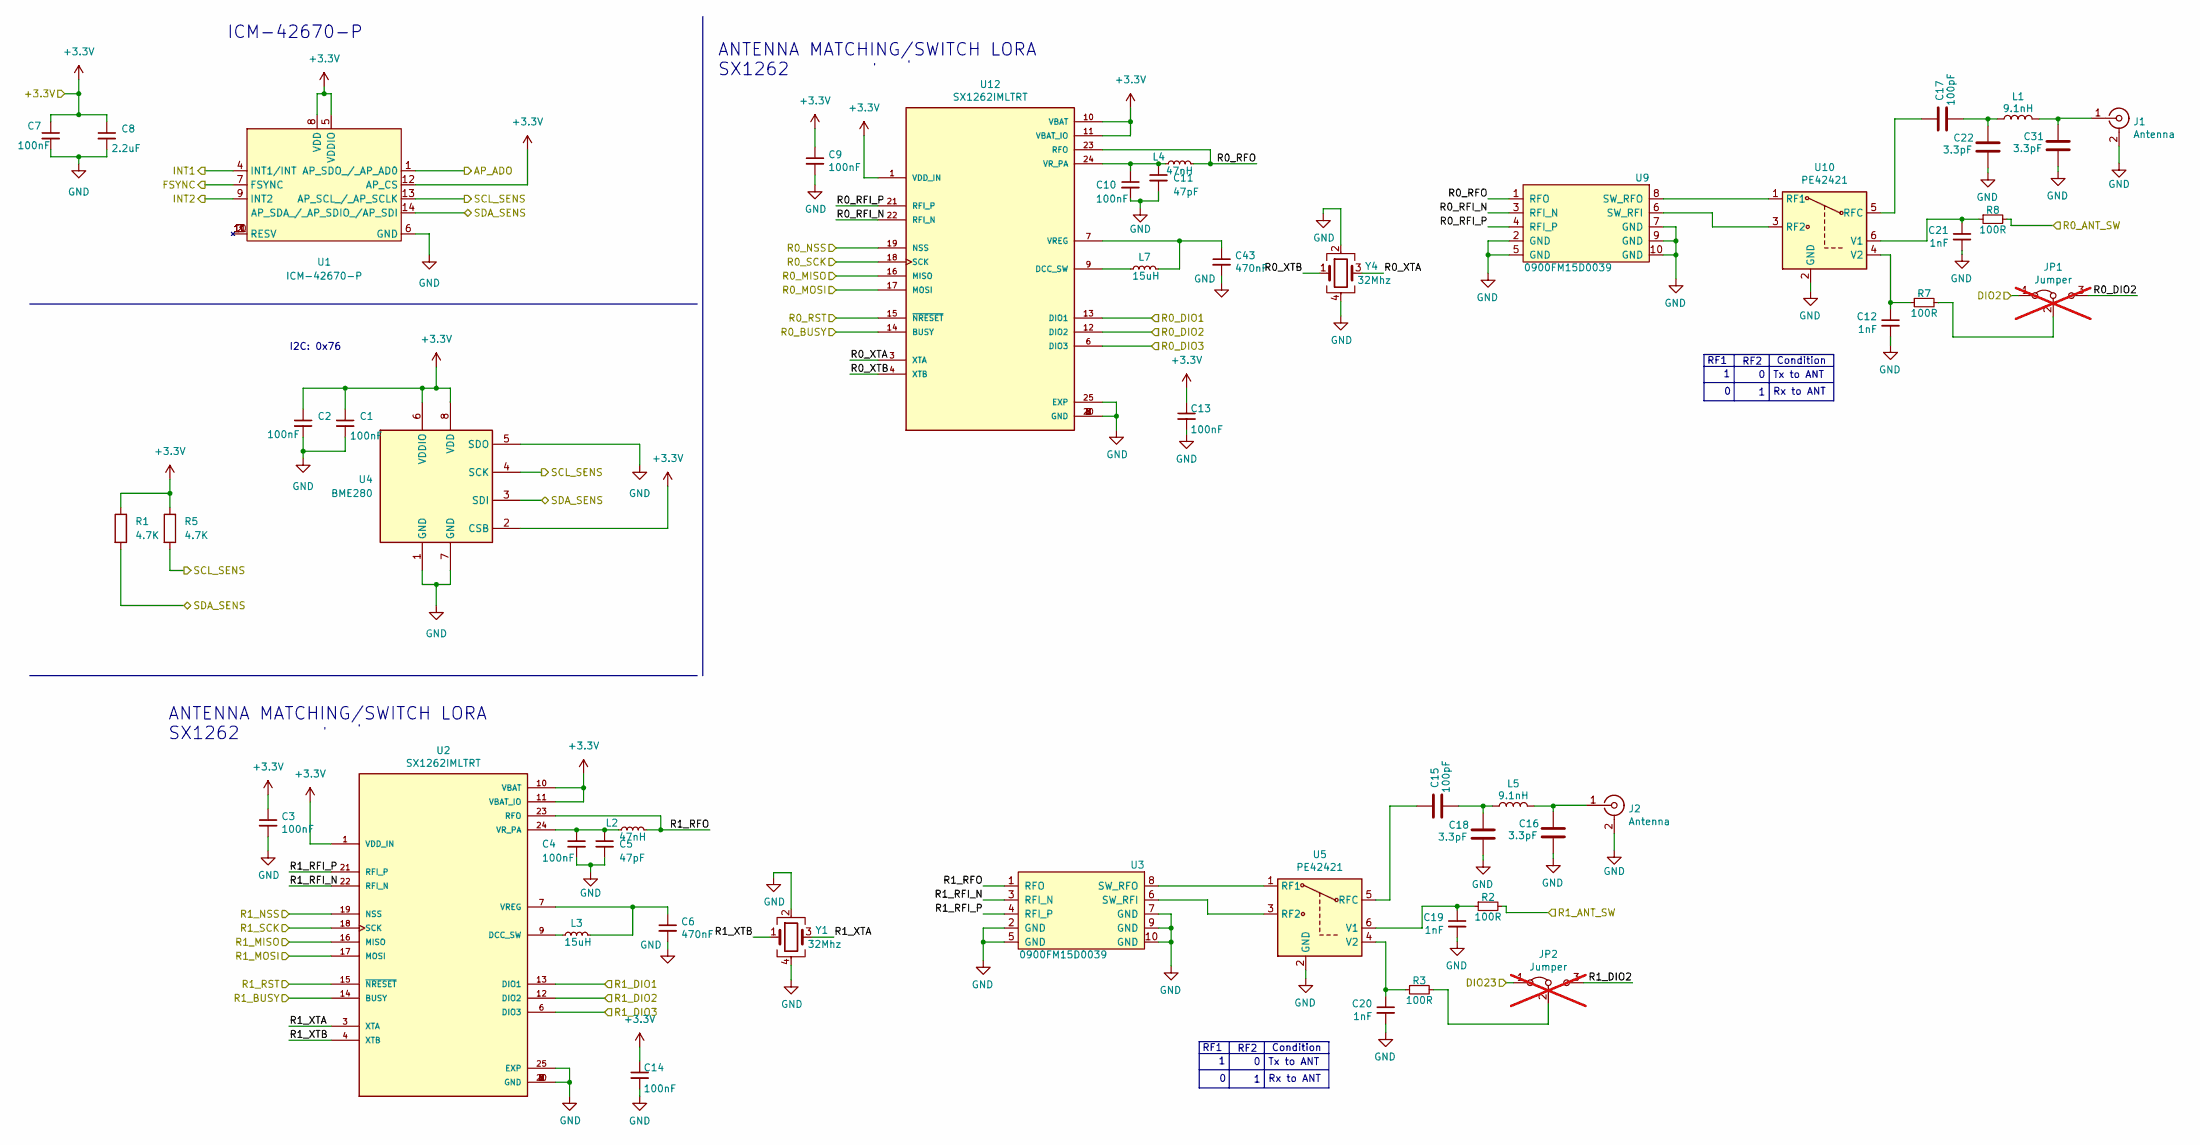
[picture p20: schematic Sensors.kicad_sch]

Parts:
C1, C2, C3, C4, C7, C9, C10, C13, C14: 100nF; C_0402_1005Metric; LCSC# C56392
C5, C11: 47pF; C_0402_1005Metric; LCSC# C437519
C6, C43: 470nF; C_0402_1005Metric; LCSC# C47339
C8: 2.2uF; C_0402_1005Metric; LCSC# C170151
C12, C19, C20, C21: 1nF; C_0402_1005Metric; LCSC# C76947
C15, C17: 100pF; C_0402_1005Metric; LCSC# C541374
C16, C18, C22, C31: 3.3pF; C_0402_1005Metric; LCSC# C1565
J1, J2: Antenna; SMA_EDGE; LCSC# C530661
JP1, JP2: Jumper; SolderJumper-3_P1.3mm_Bridged12_RoundedPad1.0x1.5mm_NumberL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; LCSC# ---; not fitted
L1, L5: 9.1nH; L_0603_1608Metric; LCSC# C395094
L2, L4: 47nH; L_0603_1608Metric; LCSC# C578001
L3, L7: 15uH; L_0603_1608Metric; LCSC# C2885870
R1, R5: 4.7K; R_0402_1005Metric_Pad0.72x0.64mm_HandSolder; LCSC# C400631
R2, R3, R7, R8: 100R; R_0402_1005Metric; LCSC# C25076
U1: ICM-42670-P; LGA-14_3x2.5mm_P0.5mm_LayoutBorder3x4y; LCSC# C3288646
U2, U12: SX1262IMLTRT; QFN-24-1EP_4x4mm_P0.5mm_EP2.65x2.65mm; Mouser# 947-SX1262IMLTRT
U3, U9: 0900FM15D0039; 0900FM15D0039E; Mouser# 609-0900FM15D0039E
U4: BME280; Bosch_LGA-8_2.5x2.5mm_P0.65mm_ClockwisePinNumbering; LCSC# C92489
U5, U10: PE42421; SOT-363_SC-70-6; Mouser# 81-PE42421SCAA-Z; LCSC# C470893
Y1, Y4: 32Mhz; Crystal_SMD_2520-4Pin_2.5x2.0mm; LCSC# C255969

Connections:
+3.3V: C1.1, C2.1, C3.1, C7.1, C8.1, C9.1, C13.1, C14.1, R1.1, R5.1, U1.5 (VDDIO), U1.8 (VDD), U1.12 (AP_CS), U2.1 (VDD_IN), U2.10 (VBAT), U2.11 (VBAT_IO), U4.2 (CSB), U4.6 (VDDIO), U4.8 (VDD), U12.1 (VDD_IN), U12.10 (VBAT), U12.11 (VBAT_IO); also elsewhere on the board
/Inputs_Connectors/AP_ADO: U1.1 (AP_SDO_/_AP_AD0); also elsewhere on the board
/Inputs_Connectors/DIO2: JP1.1 (A); also elsewhere on the board
/Inputs_Connectors/DIO23: JP2.1 (A); also elsewhere on the board
/Inputs_Connectors/FSYNC: U1.7 (FSYNC); also elsewhere on the board
/Inputs_Connectors/INT1: U1.4 (INT1/INT); also elsewhere on the board
/Inputs_Connectors/INT2: U1.9 (INT2); also elsewhere on the board
/Inputs_Connectors/R0_ANT_SW: R8.2; also elsewhere on the board
/Inputs_Connectors/R0_BUSY: U12.14 (BUSY); also elsewhere on the board
/Inputs_Connectors/R0_DIO1: U12.13 (DIO1); also elsewhere on the board
/Inputs_Connectors/R0_DIO3: U12.6 (DIO3); also elsewhere on the board
/Inputs_Connectors/R0_MISO: U12.16 (MISO); also elsewhere on the board
/Inputs_Connectors/R0_MOSI: U12.17 (MOSI); also elsewhere on the board
/Inputs_Connectors/R0_NSS: U12.19 (NSS); also elsewhere on the board
/Inputs_Connectors/R0_RST: U12.15 (~NRESET); also elsewhere on the board
/Inputs_Connectors/R0_SCK: U12.18 (SCK); also elsewhere on the board
/Inputs_Connectors/R1_ANT_SW: R2.2; also elsewhere on the board
/Inputs_Connectors/R1_BUSY: U2.14 (BUSY); also elsewhere on the board
/Inputs_Connectors/R1_DIO1: U2.13 (DIO1); also elsewhere on the board
/Inputs_Connectors/R1_DIO3: U2.6 (DIO3); also elsewhere on the board
/Inputs_Connectors/R1_MISO: U2.16 (MISO); also elsewhere on the board
/Inputs_Connectors/R1_MOSI: U2.17 (MOSI); also elsewhere on the board
/Inputs_Connectors/R1_NSS: U2.19 (NSS); also elsewhere on the board
/Inputs_Connectors/R1_RST: U2.15 (~NRESET); also elsewhere on the board
/Inputs_Connectors/R1_SCK: U2.18 (SCK); also elsewhere on the board
/Inputs_Connectors/SCL_SENS: R5.2, U1.13 (AP_SCL_/_AP_SCLK), U4.4 (SCK); also elsewhere on the board
/Inputs_Connectors/SDA_SENS: R1.2, U1.14 (AP_SDA_/_AP_SDIO_/AP_SDI), U4.3 (SDI); also elsewhere on the board
/Sensors/R0_DIO2: JP1.3 (B), U12.12 (DIO2); also elsewhere on the board
/Sensors/R0_RFI_N: U9.3 (RFI_N), U12.22 (RFI_N)
/Sensors/R0_RFI_P: U9.4 (RFI_P), U12.21 (RFI_P)
/Sensors/R0_RFO: L4.2, U9.1 (RFO), U12.23 (RFO)
/Sensors/R0_XTA: U12.3 (XTA), Y4.3
/Sensors/R0_XTB: U12.4 (XTB), Y4.1
/Sensors/R1_DIO2: JP2.3 (B), U2.12 (DIO2); also elsewhere on the board
/Sensors/R1_RFI_N: U2.22 (RFI_N), U3.3 (RFI_N)
/Sensors/R1_RFI_P: U2.21 (RFI_P), U3.4 (RFI_P)
/Sensors/R1_RFO: L2.2, U2.23 (RFO), U3.1 (RFO)
/Sensors/R1_XTA: U2.3 (XTA), Y1.3
/Sensors/R1_XTB: U2.4 (XTB), Y1.1
GND: C1.2, C2.2, C3.2, C4.2, C5.2, C6.2, C7.2, C8.2, C9.2, C10.2, C11.2, C12.2, C13.2, C14.2, C16.2, C18.2, C19.2, C20.2, C21.2, C22.2, C31.2, C43.2, J1.2 (Ext), J2.2 (Ext), U1.6 (GND), U2.2 (GND), U2.5 (GND), U2.8 (GND), U2.20 (GND), U2.25 (EXP), U3.2 (GND), U3.5 (GND), U3.7 (GND), U3.9 (GND), U3.10 (GND), U4.1 (GND), U4.5 (SDO), U4.7 (GND), U5.2 (GND), U9.2 (GND), U9.5 (GND), U9.7 (GND), U9.9 (GND), U9.10 (GND), U10.2 (GND), U12.2 (GND), U12.5 (GND), U12.8 (GND), U12.20 (GND), U12.25 (EXP), Y1.2, Y1.4, Y4.2, Y4.4; also elsewhere on the board
unnamed: C15.2, C18.1, L5.2
unnamed: C17.2, C22.1, L1.2
unnamed: C31.1, J1.1 (In), L1.1
unnamed: C16.1, J2.1 (In), L5.1
unnamed: JP1.2 (C), R7.2
unnamed: JP2.2 (C), R3.2
unnamed: L3.1, U2.9 (DCC_SW)
unnamed: C6.1, L3.2, U2.7 (VREG)
unnamed: C4.1, C5.1, L2.1, U2.24 (VR_PA)
unnamed: U3.6 (SW_RFI), U5.3 (RF2)
unnamed: U3.8 (SW_RFO), U5.1 (RF1)
unnamed: C15.1, U5.5 (RFC)
unnamed: C19.1, R2.1, U5.6 (V1)
unnamed: C20.1, R3.1, U5.4 (V2)
unnamed: U9.8 (SW_RFO), U10.1 (RF1)
unnamed: U9.6 (SW_RFI), U10.3 (RF2)
unnamed: C17.1, U10.5 (RFC)
unnamed: C21.1, R8.1, U10.6 (V1)
unnamed: C12.1, R7.1, U10.4 (V2)
unnamed: L7.1, U12.9 (DCC_SW)
unnamed: C43.1, L7.2, U12.7 (VREG)
unnamed: C10.1, C11.1, L4.1, U12.24 (VR_PA)

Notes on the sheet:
ANTENNA MATCHING/SWITCH LORA
Condition
Tx to ANT
SX1262
RF2
RF1
Rx to ANT
I2C: 0x76
ICM-42670-P

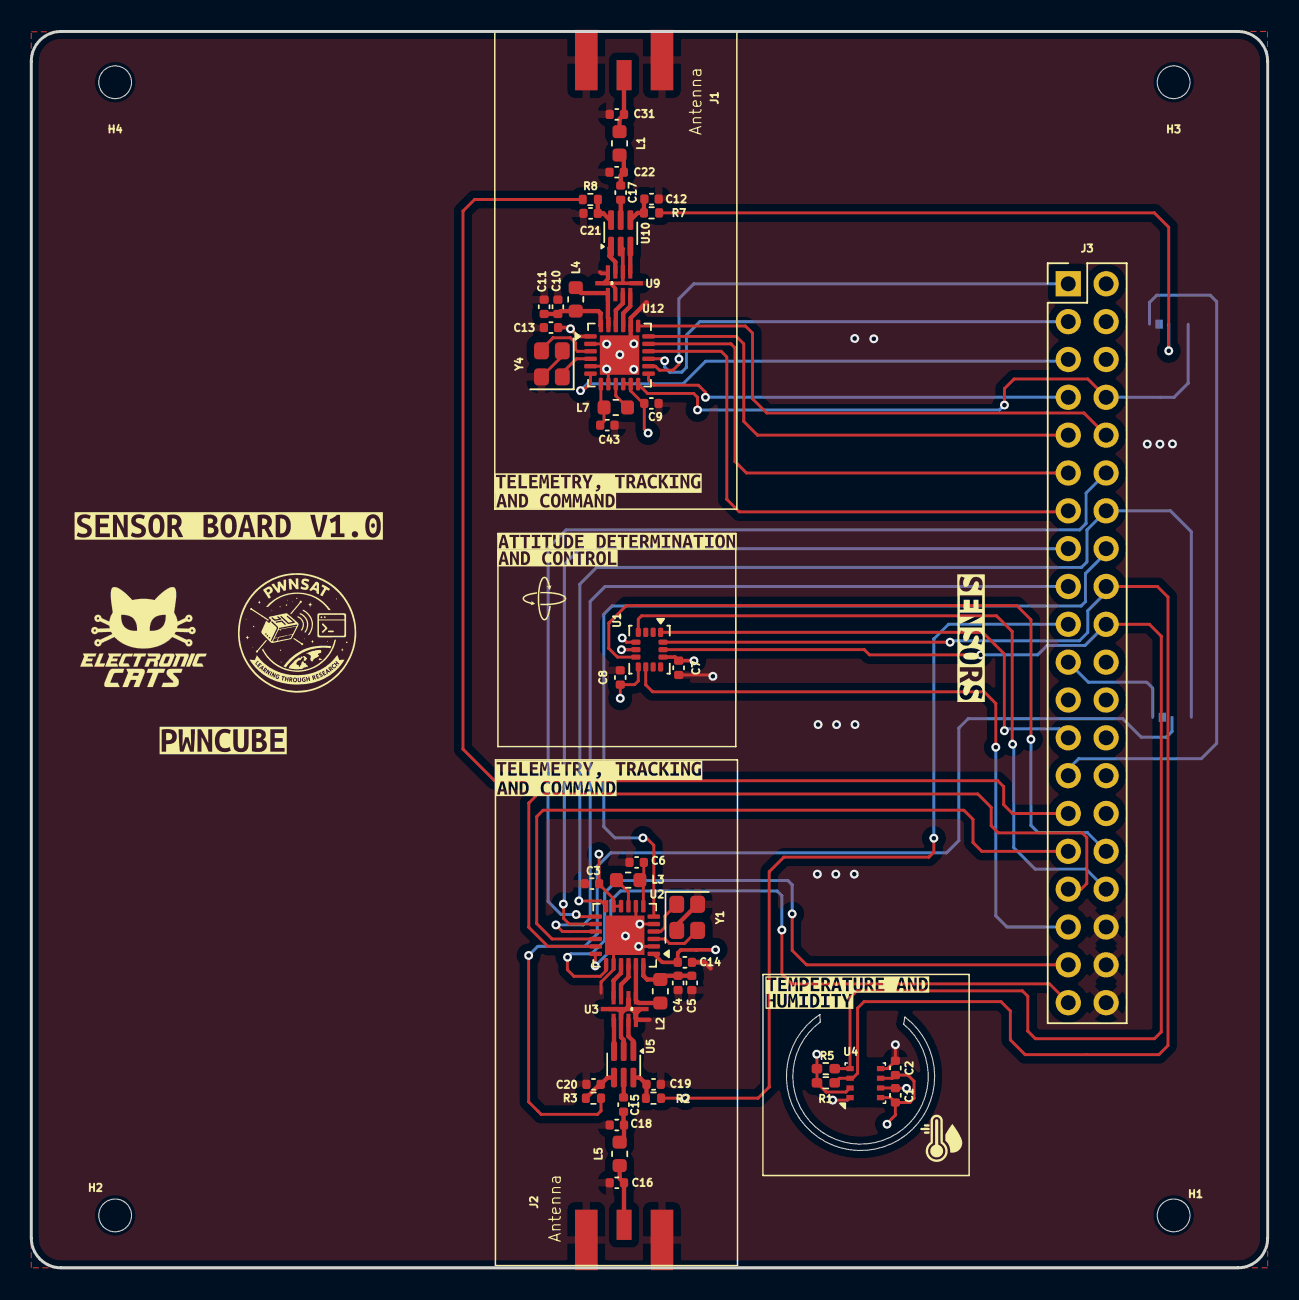
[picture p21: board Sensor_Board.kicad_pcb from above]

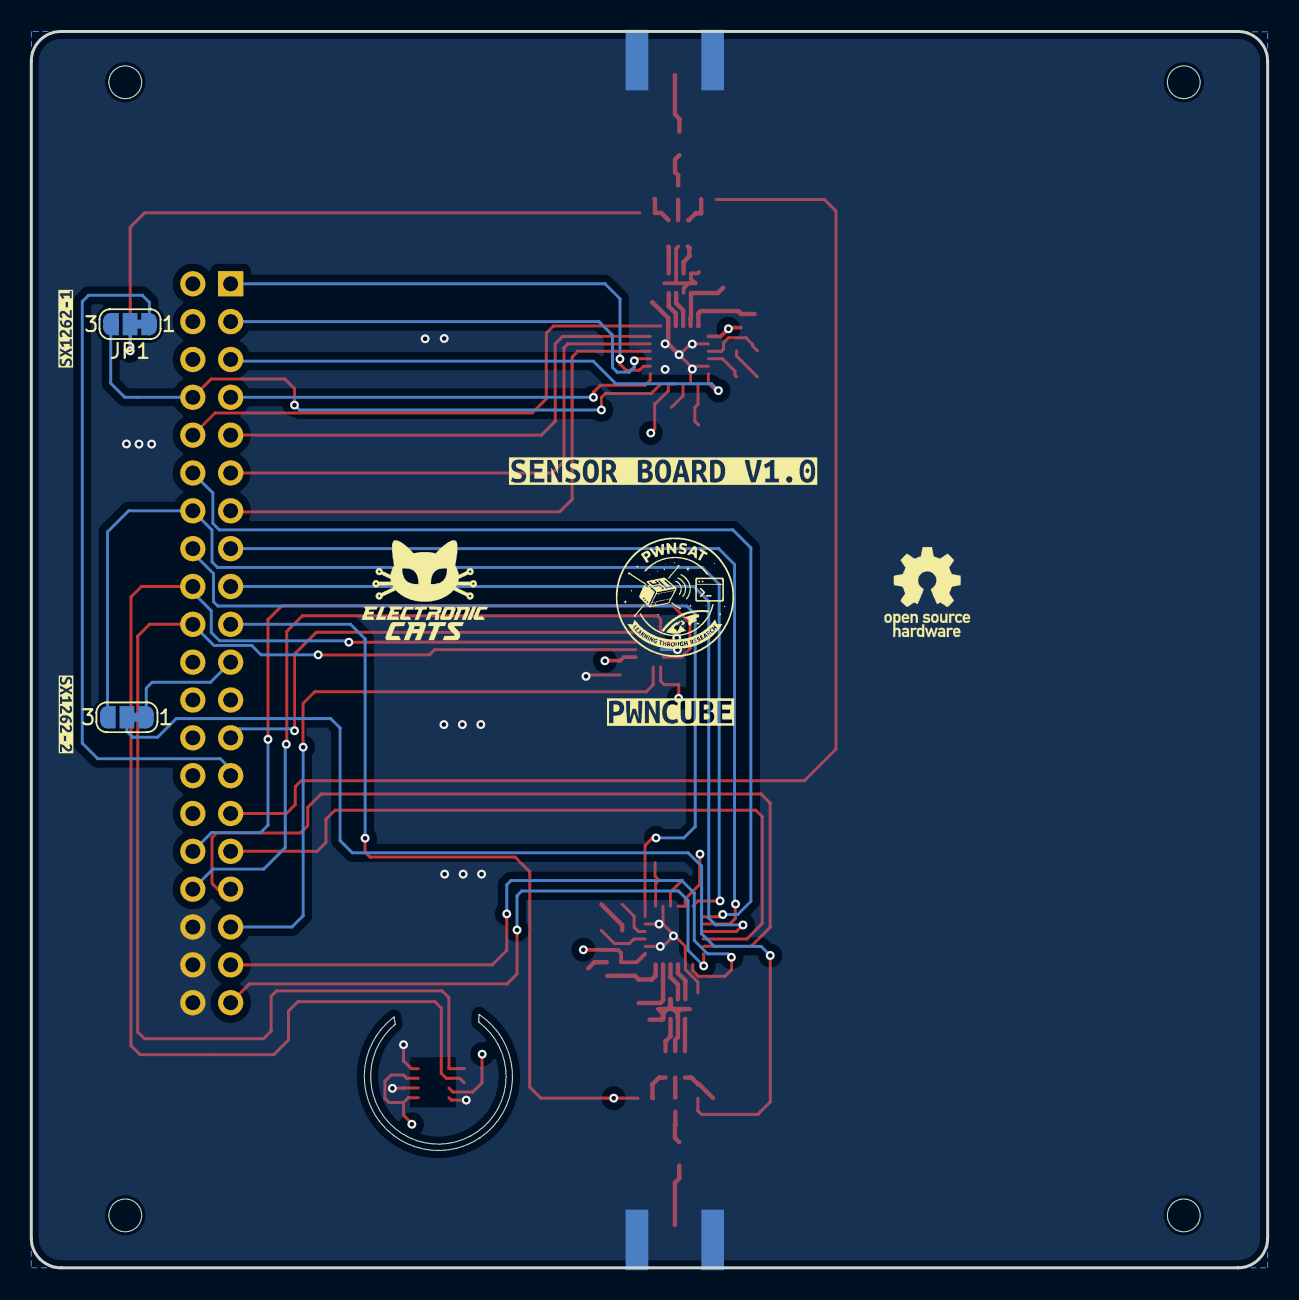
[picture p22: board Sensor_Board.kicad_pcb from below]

Board: 4 copper layers, 83.0 x 83.0 mm, 70 parts (6 on the bottom side), 62 nets.

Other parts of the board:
H1, H2, H3, H4: MountingHole; MountingHole_2.2mm_M2
kibuzzard-69860F52: G***; kibuzzard-69860F52
kibuzzard-69860F65: G***; kibuzzard-69860F65
kibuzzard-69866AEC: G***; kibuzzard-69866AEC
kibuzzard-69866B09: G***; kibuzzard-69866B09
kibuzzard-698518BF, kibuzzard-698518BF#2: G***; kibuzzard-698518BF
kibuzzard-698518EC, kibuzzard-698518EC#2: G***; kibuzzard-698518EC
kibuzzard-698668F8: G***; kibuzzard-698668F8
kibuzzard-698669D4, kibuzzard-698669D4#2: G***; kibuzzard-698669D4
kibuzzard-698669E3, kibuzzard-698669E3#2: G***; kibuzzard-698669E3
kibuzzard-6985197E: G***; kibuzzard-6985197E
kibuzzard-69866904: G***; kibuzzard-69866904

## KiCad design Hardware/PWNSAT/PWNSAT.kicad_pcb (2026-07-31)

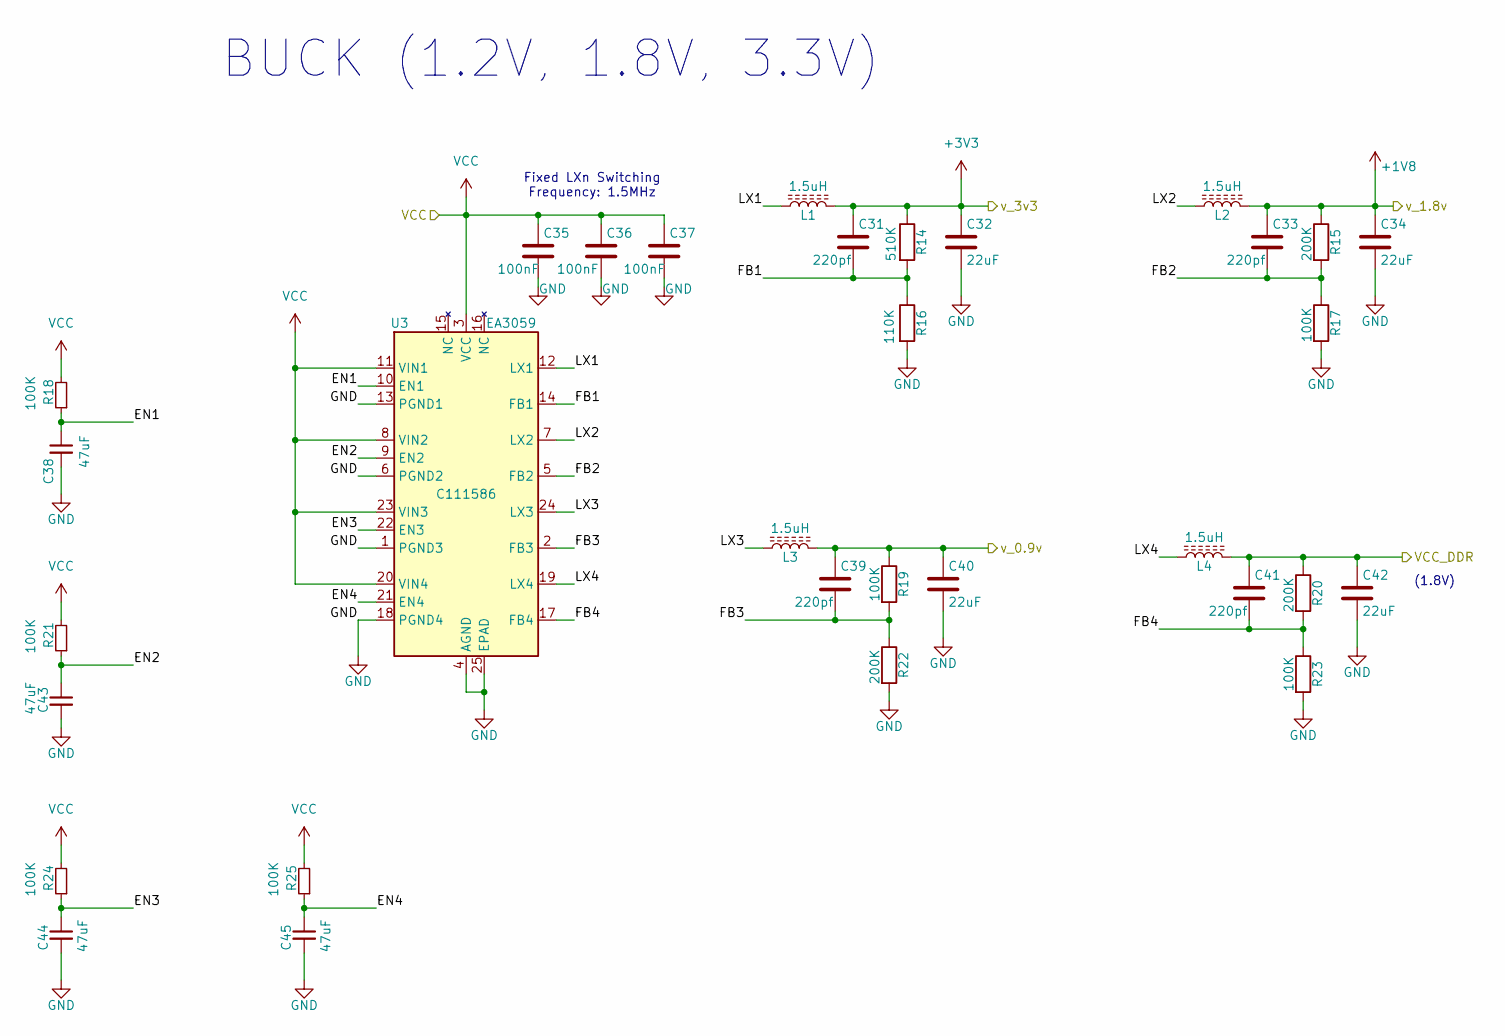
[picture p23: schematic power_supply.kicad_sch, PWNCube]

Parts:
C31, C33, C39, C41: 220pf; C_0402_1005Metric_Pad0.74x0.62mm_HandSolder; LCSC# C327000
C32, C34, C40, C42: 22uF; C_0402_1005Metric; LCSC# C415703
C35, C36, C37: 100nF; C_0402_1005Metric_Pad0.74x0.62mm_HandSolder; LCSC# C56392
C38, C43, C44, C45: 47uF; C_0603_1608Metric; LCSC# C140782
L1, L2, L3, L4: 1.5uH; L_1008_2520Metric; LCSC# C7427193
R14: 510K; R_0402_1005Metric_Pad0.72x0.64mm_HandSolder; LCSC# C365024
R15, R20, R22: 200K; R_0402_1005Metric_Pad0.72x0.64mm_HandSolder; LCSC# C364966
R16: 110K; R_0402_1005Metric_Pad0.72x0.64mm_HandSolder; LCSC# C854086
R17, R18, R19, R21, R23, R24, R25: 100K; R_0402_1005Metric_Pad0.72x0.64mm_HandSolder; LCSC# C844674
U3: EA3059; VQFN-24-1EP_4x4mm_P0.5mm_EP2.5x2.5mm; LCSC# C111586

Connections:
+1V8: C33.1, C34.1, L2.2, R15.1; also elsewhere on the board
+3V3: C31.1, C32.1, L1.2, R14.1; also elsewhere on the board
/core/VCC_DDR: C41.1, C42.1, L4.2, R20.1; also elsewhere on the board
/core/VDD_ARM: C39.1, C40.1, L3.2, R19.1; also elsewhere on the board
/power_supply/EN1: C38.1, R18.1, U3.10 (EN1)
/power_supply/EN2: C43.1, R21.1, U3.9 (EN2)
/power_supply/EN3: C44.1, R24.1, U3.22 (EN3)
/power_supply/EN4: C45.1, R25.1, U3.21 (EN4)
/power_supply/FB1: C31.2, R14.2, R16.1, U3.14 (FB1)
/power_supply/FB2: C33.2, R15.2, R17.1, U3.5 (FB2)
/power_supply/FB3: C39.2, R19.2, R22.1, U3.2 (FB3)
/power_supply/FB4: C41.2, R20.2, R23.1, U3.17 (FB4)
/power_supply/LX1: L1.1, U3.12 (LX1)
/power_supply/LX2: L2.1, U3.7 (LX2)
/power_supply/LX3: L3.1, U3.24 (LX3)
/power_supply/LX4: L4.1, U3.19 (LX4)
GND: C32.2, C34.2, C35.2, C36.2, C37.2, C38.2, C40.2, C42.2, C43.2, C44.2, C45.2, R16.2, R17.2, R22.2, R23.2, U3.1 (PGND3), U3.4 (AGND), U3.6 (PGND2), U3.13 (PGND1), U3.18 (PGND4), U3.25 (EPAD); also elsewhere on the board
VCC: C35.1, C36.1, C37.1, R18.2, R21.2, R24.2, R25.2, U3.3 (VCC), U3.8 (VIN2), U3.11 (VIN1), U3.20 (VIN4), U3.23 (VIN3); also elsewhere on the board

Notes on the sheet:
BUCK (1.2V, 1.8V, 3.3V)
Fixed LXn Switching Frequency: 1.5MHz
(1.8V)

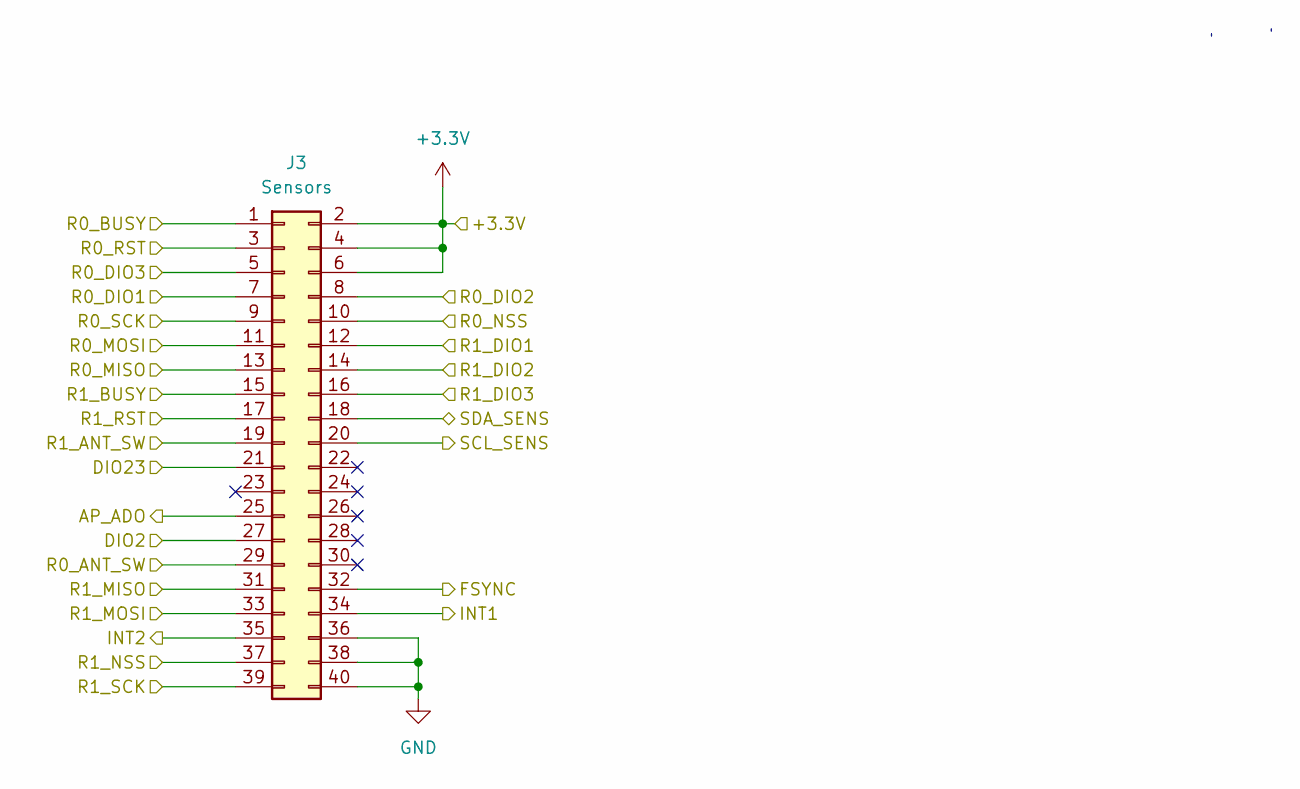
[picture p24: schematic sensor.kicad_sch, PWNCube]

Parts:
J3: Sensors; PinHeader_2x20_P2.54mm_Vertical; LCSC# C7501249

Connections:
+3.3V: J3.2, J3.4, J3.6; also elsewhere on the board
/Sensor/AP_ADO: J3.25; also elsewhere on the board
/Sensor/DIO2: J3.27; also elsewhere on the board
/Sensor/DIO23: J3.21; also elsewhere on the board
/Sensor/FSYNC: J3.32; also elsewhere on the board
/Sensor/INT1: J3.34; also elsewhere on the board
/Sensor/INT2: J3.35; also elsewhere on the board
/Sensor/R0_ANT_SW: J3.29; also elsewhere on the board
/Sensor/R0_BUSY: J3.1; also elsewhere on the board
/Sensor/R0_DIO1: J3.7; also elsewhere on the board
/Sensor/R0_DIO2: J3.8; also elsewhere on the board
/Sensor/R0_DIO3: J3.5; also elsewhere on the board
/Sensor/R0_MISO: J3.13; also elsewhere on the board
/Sensor/R0_MOSI: J3.11; also elsewhere on the board
/Sensor/R0_NSS: J3.10; also elsewhere on the board
/Sensor/R0_RST: J3.3; also elsewhere on the board
/Sensor/R0_SCK: J3.9; also elsewhere on the board
/Sensor/R1_ANT_SW: J3.19; also elsewhere on the board
/Sensor/R1_BUSY: J3.15; also elsewhere on the board
/Sensor/R1_DIO1: J3.12; also elsewhere on the board
/Sensor/R1_DIO2: J3.14; also elsewhere on the board
/Sensor/R1_DIO3: J3.16; also elsewhere on the board
/Sensor/R1_MISO: J3.31; also elsewhere on the board
/Sensor/R1_MOSI: J3.33; also elsewhere on the board
/Sensor/R1_NSS: J3.37; also elsewhere on the board
/Sensor/R1_RST: J3.17; also elsewhere on the board
/Sensor/R1_SCK: J3.39; also elsewhere on the board
/Sensor/SCL_SENS: J3.20; also elsewhere on the board
/Sensor/SDA_SENS: J3.18; also elsewhere on the board
GND: J3.36, J3.38, J3.40; also elsewhere on the board

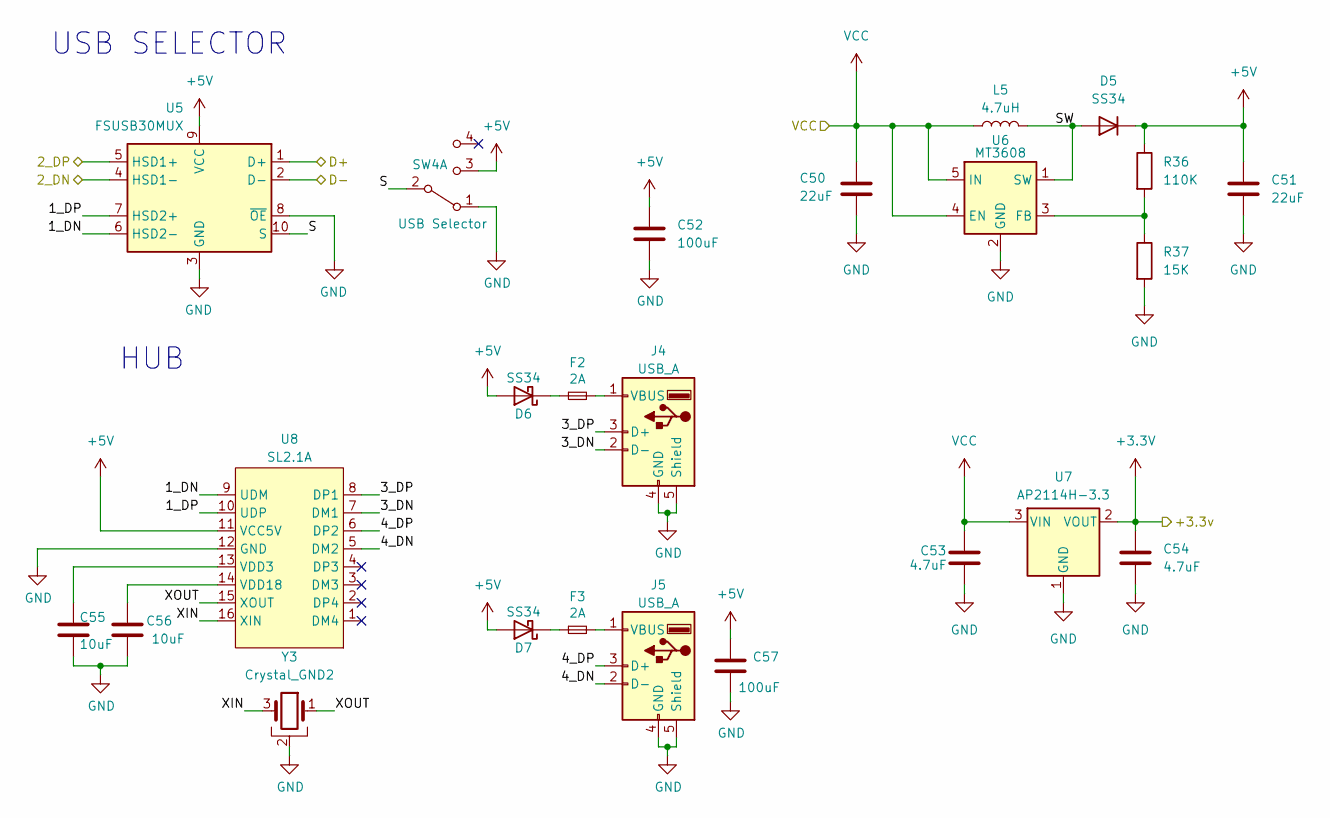
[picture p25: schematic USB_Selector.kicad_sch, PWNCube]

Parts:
C50, C51: 22uF; C_0402_1005Metric; LCSC# C415703
C52, C57: 100uF; C_0805_2012Metric; LCSC# C141660
C53, C54: 4.7uF; C_0402_1005Metric; LCSC# C368809
C55, C56: 10uF; C_0603_1608Metric; LCSC# C96446
D5, D6, D7: SS34; D_SMA; LCSC# C908680
F2, F3: 2A; Fuse_0603_1608Metric; LCSC# C41380229
J4, J5: USB_A; USB_A_Connfly_DS1095; LCSC# C2345
L5: 4.7uH; LQH5BPN; LCSC# C520334
R36: 110K; R_0603_1608Metric; LCSC# C326736
R37: 15K; R_0603_1608Metric; LCSC# C2989599
SW4: USB Selector; SW_Slide_SPDT_Angled_CK_OS102011MA1Q; LCSC# C393937
U5: FSUSB30MUX; IC_FSUSB42UMX; LCSC# C42370490
U6: MT3608; SOT-23-6; LCSC# C2932326
U7: AP2114H-3.3; SOT-223-3_TabPin2; LCSC# C150716
U8: SL2.1A; SO-16_3.9x9.9mm_P1.27mm; LCSC# C192893
Y3: Crystal_GND2; Crystal_SMD_3225-4Pin_3.2x2.5mm; LCSC# C133334

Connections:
+3.3V: C54.1, U7.2 (VOUT); also elsewhere on the board
+5V: C51.1, C52.1, C57.1, D5.1 (K), D6.2 (A), D7.2 (A), R36.1, SW4.3 (C), U5.9 (VCC), U8.11 (VCC5V)
/Source_Connector/2_DN: U5.4 (HSD1-); also elsewhere on the board
/Source_Connector/2_DP: U5.5 (HSD1+); also elsewhere on the board
/USB_Selector/1_DN: U5.6 (HSD2-), U8.9 (UDM)
/USB_Selector/1_DP: U5.7 (HSD2+), U8.10 (UDP)
/USB_Selector/3_DN: J4.2 (D-), U8.7 (DM1)
/USB_Selector/3_DP: J4.3 (D+), U8.8 (DP1)
/USB_Selector/4_DN: J5.2 (D-), U8.5 (DM2)
/USB_Selector/4_DP: J5.3 (D+), U8.6 (DP2)
/USB_Selector/D+: U5.1 (D+); also elsewhere on the board
/USB_Selector/D-: U5.2 (D-); also elsewhere on the board
/USB_Selector/S: SW4.2 (B), U5.10 (S)
/USB_Selector/SW: D5.2 (A), L5.2, U6.1 (SW)
/USB_Selector/XIN: U8.16 (XIN), Y3.3
/USB_Selector/XOUT: U8.15 (XOUT), Y3.1
GND: C50.2, C51.2, C52.2, C53.2, C54.2, C55.2, C56.1, C57.2, J4.4 (GND), J4.5 (Shield), J5.4 (GND), J5.5 (Shield), R37.2, SW4.1 (A), U5.3 (GND), U5.8 (~OE), U6.2 (GND), U7.1 (GND), U8.12 (GND), Y3.2, Y3.4; also elsewhere on the board
unnamed: D6.1 (K), F2.1
unnamed: D7.1 (K), F3.1
unnamed: F2.2, J4.1 (VBUS)
unnamed: F3.2, J5.1 (VBUS)
unnamed: R36.2, R37.1, U6.3 (FB)
unnamed: C55.1, U8.13 (VDD3)
unnamed: C56.2, U8.14 (VDD18)
VCC: C50.1, C53.1, L5.1, U6.4 (EN), U6.5 (IN), U7.3 (VIN); also elsewhere on the board

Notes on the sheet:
HUB
USB SELECTOR

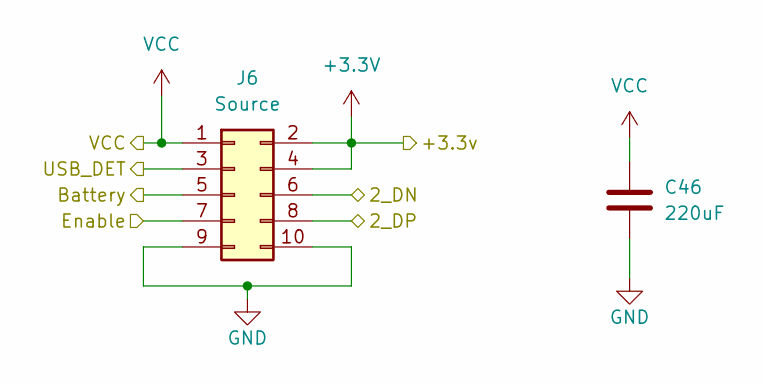
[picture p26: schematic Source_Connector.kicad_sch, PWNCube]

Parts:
C46: 220uF; C_1206_3216Metric
J6: Source; PinHeader_2x05_P2.54mm_Vertical; LCSC# C7501191

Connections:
+3.3V: J6.2, J6.4; also elsewhere on the board
/Source_Connector/2_DN: J6.6; also elsewhere on the board
/Source_Connector/2_DP: J6.8; also elsewhere on the board
/Source_Connector/Battery: J6.5; also elsewhere on the board
/Source_Connector/Enable: J6.7; also elsewhere on the board
/Source_Connector/USB_DET: J6.3; also elsewhere on the board
GND: C46.2, J6.9, J6.10; also elsewhere on the board
VCC: C46.1, J6.1; also elsewhere on the board

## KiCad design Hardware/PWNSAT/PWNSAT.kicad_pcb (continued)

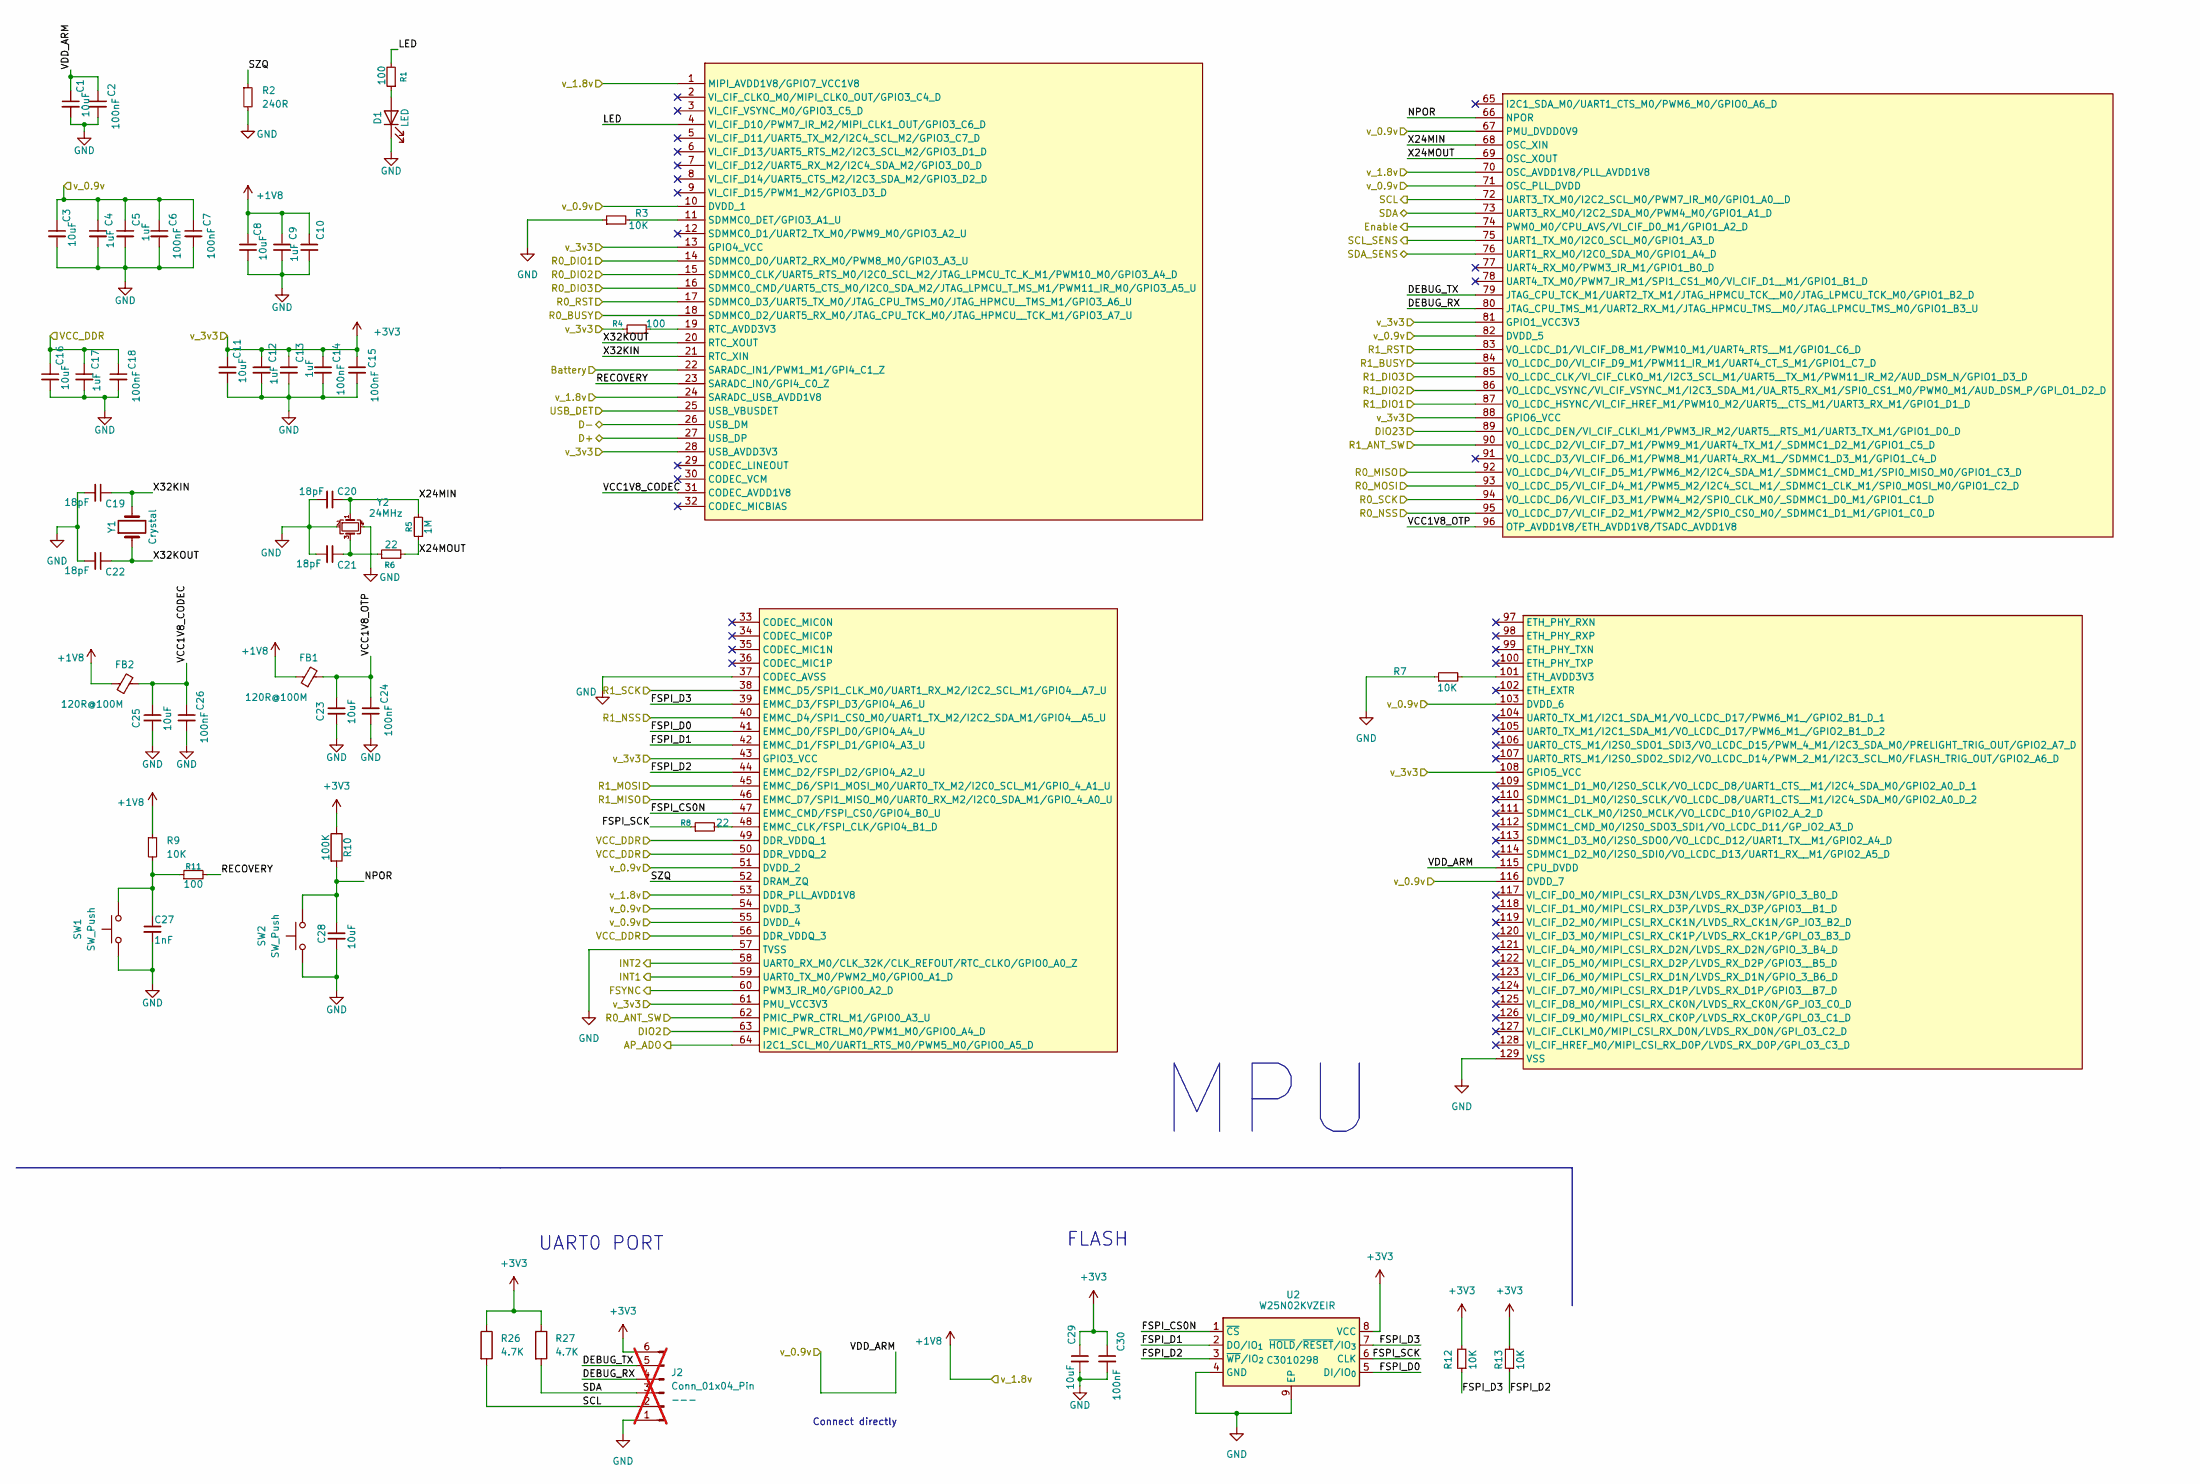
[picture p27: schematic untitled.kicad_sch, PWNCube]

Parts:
C1, C3, C8, C11, C16, C23, C25, C28, C29: 10uF; C_0603_1608Metric; LCSC# C96446
C2, C6, C7, C14, C15, C18, C24, C26, C30: 100nF; C_0402_1005Metric_Pad0.74x0.62mm_HandSolder; LCSC# C56392
C4, C5, C9, C10, C12, C13, C17: 1uF; C_0402_1005Metric_Pad0.74x0.62mm_HandSolder; LCSC# C52923
C19, C20, C21, C22: 18pF; C_0402_1005Metric_Pad0.74x0.62mm_HandSolder; LCSC# C161534
C27: 1nF; C_0402_1005Metric_Pad0.74x0.62mm_HandSolder; LCSC# C189467
D1: LED; LED_0603_1608Metric; LCSC# C375573
FB1, FB2: 120R@100M; L_0603_1608Metric; LCSC# C14709
J2: Conn_01x04_Pin; PinHeader_1x06_P2.54mm_Vertical; LCSC# ---; not fitted
R1, R4, R11: 100; R_0603_1608Metric; LCSC# C253328
R2: 240R; R_0402_1005Metric_Pad0.72x0.64mm_HandSolder; LCSC# C728568
R3, R7, R9, R12, R13: 10K; R_0402_1005Metric_Pad0.72x0.64mm_HandSolder; LCSC# C2759535
R5: 1M; R_0402_1005Metric_Pad0.72x0.64mm_HandSolder; LCSC# C131492
R6, R8: 22; R_0603_1608Metric; LCSC# C313374
R10: 100K; R_0402_1005Metric_Pad0.72x0.64mm_HandSolder; LCSC# C844674
R26, R27: 4.7K; R_0402_1005Metric_Pad0.72x0.64mm_HandSolder; LCSC# C400631
SW1, SW2: SW_Push; TS1088R02026; LCSC# C455281
U1: RV1106G3; LCSC# C5328706
U2: W25N02KVZEIR; WSON-8-1EP_8x6mm_P1.27mm_EP3.4x4.3mm; LCSC# C3010298
Y1: Crystal; Crystal_SMD_3215-2Pin_3.2x1.5mm; LCSC# C620155
Y2: 24MHz; Crystal_SMD_3225-4Pin_3.2x2.5mm; LCSC# C70590

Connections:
+1V8: C8.1, C9.1, C10.1, FB1.1, FB2.1, R9.1, U1.1 (MIPI_AVDD1V8/GPIO7_VCC1V8), U1.24 (SARADC_USB_AVDD1V8), U1.53 (DDR_PLL_AVDD1V8), U1.70 (OSC_AVDD1V8/PLL_AVDD1V8); also elsewhere on the board
+3V3: C11.1, C12.1, C13.1, C14.1, C15.1, C29.1, C30.1, J2.6, R4.1, R10.1, R12.2, R13.2, R26.1, R27.1, U1.13 (GPIO4_VCC), U1.28 (USB_AVDD3V3), U1.43 (GPIO3_VCC), U1.61 (PMU_VCC3V3), U1.81 (GPIO1_VCC3V3), U1.88 (GPIO6_VCC), U1.108 (GPIO5_VCC), U2.8 (VCC); also elsewhere on the board
/Sensor/AP_ADO: U1.64 (I2C1_SCL_M0/UART1_RTS_M0/PWM5_M0/GPIO0_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); also elsewhere on the board
/Sensor/DIO2: U1.63 (PMIC_PWR_CTRL_M0/PWM1_M0/GPIO0_A4_D); also elsewhere on the board
/Sensor/DIO23: U1.89 (VO_LCDC_DEN/VI_CIF_CLKI_M1/PWM3_IR_M2/U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); also elsewhere on the board
/Sensor/FSYNC: U1.60 (PWM3_IR_M0/GPIO0_A2_D); also elsewhere on the board
/Sensor/INT1: U1.59 (UART0_TX_M0/PWM2_M0/GPIO0_A1_D); also elsewhere on the board
/Sensor/INT2: U1.58 (UART0_RX_M0/CLK_32K/CLK_REFOUT/RTC_CLKO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); also elsewhere on the board
/Sensor/R0_ANT_SW: U1.62 (PMIC_PWR_CTRL_M1/GPIO0_A3_U); also elsewhere on the board
/Sensor/R0_BUSY: U1.18 (SDMMC0_D2/UART5_RX_M0/JTAG_CPU_TCK_M0/J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); also elsewhere on the board
/Sensor/R0_DIO1: U1.14 (SDMMC0_D0/UART2_RX_M0/PWM8_M0/GPIO3_A3_U); also elsewhere on the board
/Sensor/R0_DIO2: U1.15 (SDMMC0_CLK/UART5_RTS_M0/I2C0_SCL_M2/JTA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); also elsewhere on the board
/Sensor/R0_DIO3: U1.16 (SDMMC0_CMD/UART5_CTS_M0/I2C0_SDA_M2/JTA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); also elsewhere on the board
/Sensor/R0_MISO: U1.92 (VO_LCDC_D4/VI_CIF_D5_M1/PWM6_M2/I2C4_SD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); also elsewhere on the board
/Sensor/R0_MOSI: U1.93 (VO_LCDC_D5/VI_CIF_D4_M1/PWM5_M2/I2C4_SC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); also elsewhere on the board
/Sensor/R0_NSS: U1.95 (VO_LCDC_D7/VI_CIF_D2_M1/PWM2_M2/SPI0_CS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); also elsewhere on the board
/Sensor/R0_RST: U1.17 (SDMMC0_D3/UART5_TX_M0/JTAG_CPU_TMS_M0/J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); also elsewhere on the board
/Sensor/R0_SCK: U1.94 (VO_LCDC_D6/VI_CIF_D3_M1/PWM4_M2/SPI0_CL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); also elsewhere on the board
/Sensor/R1_ANT_SW: U1.90 (VO_LCDC_D2/VI_CIF_D7_M1/PWM9_M1/UART4_T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); also elsewhere on the board
/Sensor/R1_BUSY: U1.84 (VO_LCDC_D0/VI_CIF_D9_M1/PWM11_IR_M1/UAR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); also elsewhere on the board
/Sensor/R1_DIO1: U1.87 (VO_LCDC_HSYNC/VI_CIF_HREF_M1/PWM10_M2/U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); also elsewhere on the board
/Sensor/R1_DIO2: U1.86 (VO_LCDC_VSYNC/VI_CIF_VSYNC_M1/I2C3_SDA_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); also elsewhere on the board
/Sensor/R1_DIO3: U1.85 (VO_LCDC_CLK/VI_CIF_CLKO_M1/I2C3_SCL_M1/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); also elsewhere on the board
/Sensor/R1_MISO: U1.46 (EMMC_D7/SPI1_MISO_M0/UART0_RX_M2/I2C0_S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); also elsewhere on the board
/Sensor/R1_MOSI: U1.45 (EMMC_D6/SPI1_MOSI_M0/UART0_TX_M2/I2C0_S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); also elsewhere on the board
/Sensor/R1_NSS: U1.40 (EMMC_D4/SPI1_CS0_M0/UART1_TX_M2/I2C2_SD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); also elsewhere on the board
/Sensor/R1_RST: U1.83 (VO_LCDC_D1/VI_CIF_D8_M1/PWM10_M1/UART4_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); also elsewhere on the board
/Sensor/R1_SCK: U1.38 (EMMC_D5/SPI1_CLK_M0/UART1_RX_M2/I2C2_SC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); also elsewhere on the board
/Sensor/SCL_SENS: U1.75 (UART1_TX_M0/I2C0_SCL_M0/GPIO1_A3_D); also elsewhere on the board
/Sensor/SDA_SENS: U1.76 (UART1_RX_M0/I2C0_SDA_M0/GPIO1_A4_D); also elsewhere on the board
/Source_Connector/Battery: U1.22 (SARADC_IN1/PWM1_M1/GPI4_C1_Z); also elsewhere on the board
/Source_Connector/Enable: U1.74 (PWM0_M0/CPU_AVS/VI_CIF_D0_M1/GPIO1_A2_D); also elsewhere on the board
/Source_Connector/USB_DET: U1.25 (USB_VBUSDET); also elsewhere on the board
/USB_Selector/D+: U1.27 (USB_DP); also elsewhere on the board
/USB_Selector/D-: U1.26 (USB_DM); also elsewhere on the board
/core/DEBUG_RX: J2.4, U1.80 (JTAG_CPU_TMS_M1/UART2_RX_M1/JTAG_HPMCU_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)
/core/DEBUG_TX: J2.5, U1.79 (JTAG_CPU_TCK_M1/UART2_TX_M1/JTAG_HPMCU_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)
/core/FSPI_CS0N: U1.47 (EMMC_CMD/FSPI_CS0/GPIO4_B0_U), U2.1 (~CS)
/core/FSPI_D0: U1.41 (EMMC_D0/FSPI_D0/GPIO4_A4_U), U2.5 (DI/IO_{0})
/core/FSPI_D1: U1.42 (EMMC_D1/FSPI_D1/GPIO4_A3_U), U2.2 (DO/IO_{1})
/core/FSPI_D2: R13.1, U1.44 (EMMC_D2/FSPI_D2/GPIO4_A2_U), U2.3 (~WP/IO_{2})
/core/FSPI_D3: R12.1, U1.39 (EMMC_D3/FSPI_D3/GPIO4_A6_U), U2.7 (~HOLD/~RESET/IO_{3})
/core/FSPI_SCK: R8.1, U2.6 (CLK)
/core/LED: R1.2, U1.4 (VI_CIF_D10/PWM7_IR_M2/MIPI_CLK1_OUT/GPI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)
/core/NPOR: C28.1, R10.2, SW2.2, U1.66 (NPOR)
/core/RECOVERY: R11.2, U1.23 (SARADC_IN0/GPI4_C0_Z)
/core/SCL: J2.2, R26.2, U1.72 (UART3_TX_M0/I2C2_SCL_M0/PWM7_IR_M0/GPIO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)
/core/SDA: J2.3, R27.2, U1.73 (UART3_RX_M0/I2C2_SDA_M0/PWM4_M0/GPIO1_A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)
/core/SZQ: R2.1, U1.52 (DRAM_ZQ)
/core/VCC1V8_CODEC: C25.1, C26.1, FB2.2, U1.31 (CODEC_AVDD1V8)
/core/VCC1V8_OTP: C23.1, C24.1, FB1.2, U1.96 (OTP_AVDD1V8/ETH_AVDD1V8/TSADC_AVDD1V8)
/core/VCC_DDR: C16.1, C17.1, C18.1, U1.49 (DDR_VDDQ_1), U1.50 (DDR_VDDQ_2), U1.56 (DDR_VDDQ_3); also elsewhere on the board
/core/VDD_ARM: C1.1, C2.1, C3.1, C4.1, C5.1, C6.1, C7.1, U1.10 (DVDD_1), U1.51 (DVDD_2), U1.54 (DVDD_3), U1.55 (DVDD_4), U1.67 (PMU_DVDD0V9), U1.71 (OSC_PLL_DVDD), U1.82 (DVDD_5), U1.103 (DVDD_6), U1.115 (CPU_DVDD), U1.116 (DVDD_7); also elsewhere on the board
/core/X24MIN: C20.1, R5.1, U1.68 (OSC_XIN), Y2.1
/core/X24MOUT: R5.2, R6.2, U1.69 (OSC_XOUT)
/core/X32KIN: C19.1, U1.21 (RTC_XIN), Y1.2
/core/X32KOUT: C22.1, U1.20 (RTC_XOUT), Y1.1
GND: C1.2, C2.2, C3.2, C4.2, C5.2, C6.2, C7.2, C8.2, C9.2, C10.2, C11.2, C12.2, C13.2, C14.2, C15.2, C16.2, C17.2, C18.2, C19.2, C20.2, C21.2, C22.2, C23.2, C24.2, C25.2, C26.2, C27.2, C28.2, C29.2, C30.2, D1.1 (K), J2.1, R2.2, R3.1, R7.1, SW1.1, SW2.1, U1.37 (CODEC_AVSS), U1.57 (TVSS), U1.129 (VSS), U2.4 (GND), U2.9 (EP), Y2.2, Y2.4; also elsewhere on the board
unnamed: C21.1, R6.1, Y2.3
unnamed: C27.1, R9.2, R11.1, SW1.2
unnamed: D1.2 (A), R1.1
unnamed: R4.2, U1.19 (RTC_AVDD3V3)
unnamed: R3.2, U1.11 (SDMMC0_DET/GPIO3_A1_U)
unnamed: R8.2, U1.48 (EMMC_CLK/FSPI_CLK/GPIO4_B1_D)
unnamed: R7.2, U1.101 (ETH_AVDD3V3)

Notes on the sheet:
FLASH
UART0 PORT
MPU
Connect directly

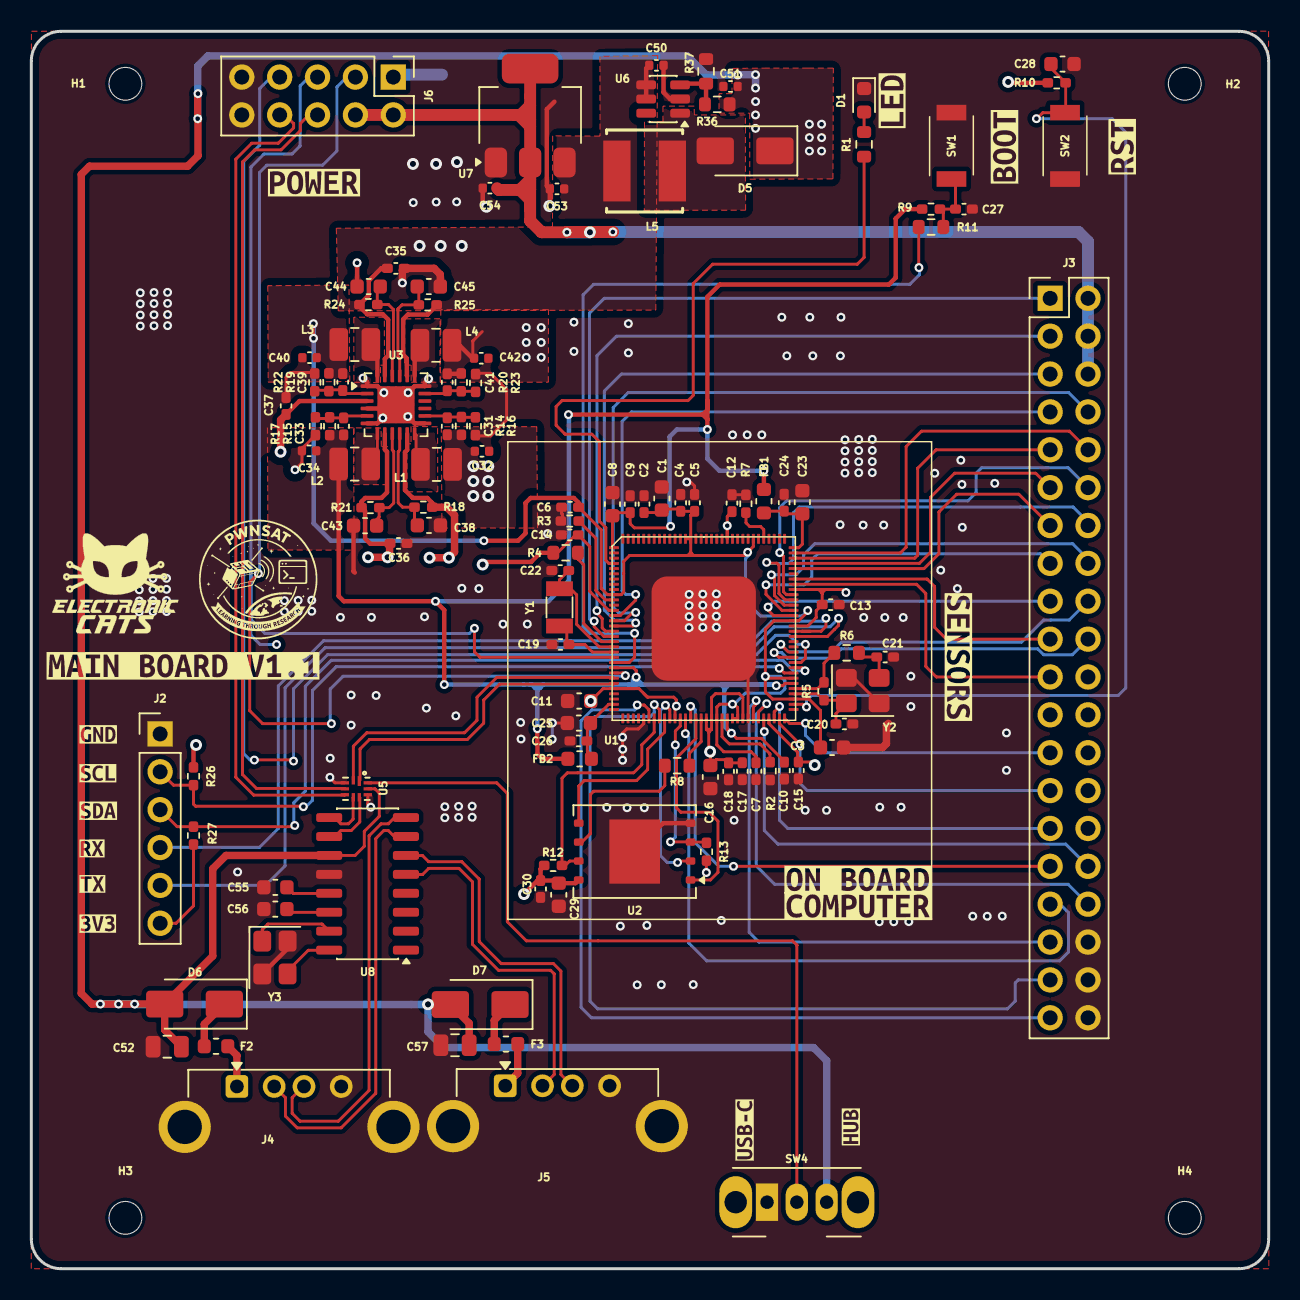
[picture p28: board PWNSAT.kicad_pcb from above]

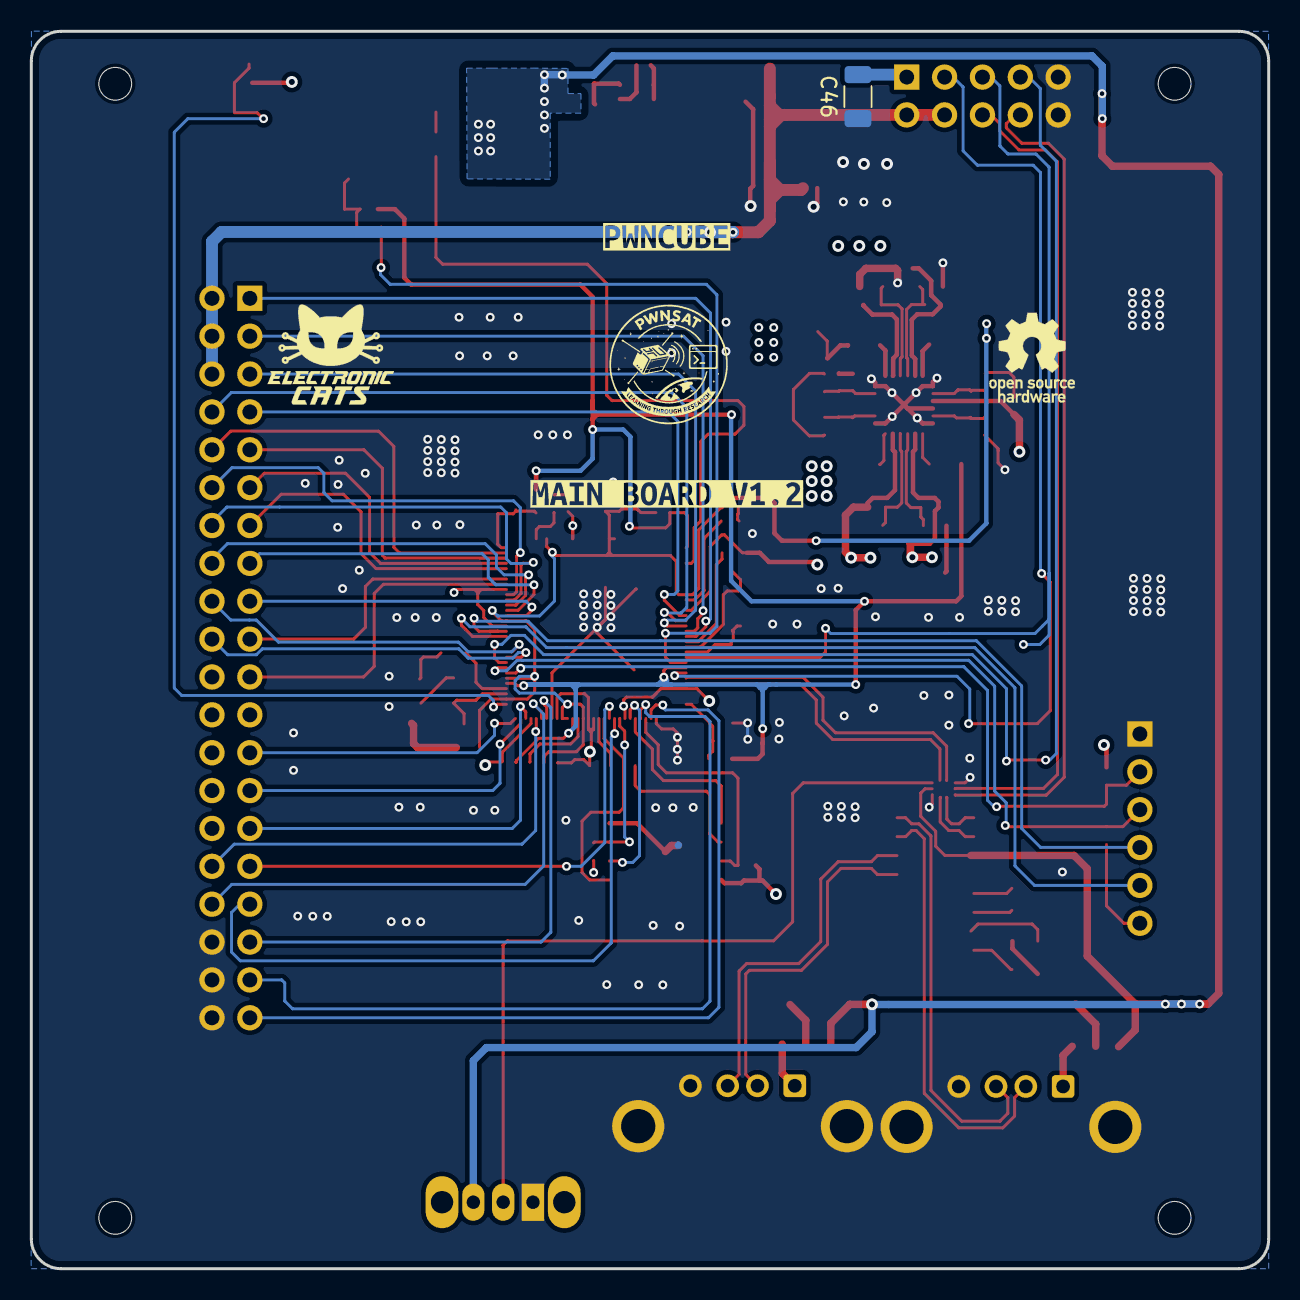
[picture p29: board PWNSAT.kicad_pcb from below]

Board: 4 copper layers, 83.0 x 83.0 mm, 136 parts (3 on the bottom side), 99 nets.

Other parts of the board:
H1, H2, H3, H4: MountingHole; MountingHole_2.2mm_M2
kibuzzard-69B43A9C: G***; kibuzzard-69B43A9C
kibuzzard-69B883B0: G***; kibuzzard-69B883B0
kibuzzard-6989FAE0: G***; kibuzzard-6989FAE0
kibuzzard-6989FAEE: G***; kibuzzard-6989FAEE
kibuzzard-698516AC: G***; kibuzzard-698516AC
kibuzzard-698516D4: G***; kibuzzard-698516D4
kibuzzard-698516F5: G***; kibuzzard-698516F5
kibuzzard-698517BF: G***; kibuzzard-698517BF
kibuzzard-698517CD: G***; kibuzzard-698517CD
kibuzzard-698517E4: G***; kibuzzard-698517E4
kibuzzard-698517F0: G***; kibuzzard-698517F0
kibuzzard-698615E5: G***; kibuzzard-698615E5
kibuzzard-6985157B: G***; kibuzzard-6985157B
kibuzzard-6985168F: G***; kibuzzard-6985168F
kibuzzard-6986164F: G***; kibuzzard-6986164F
kibuzzard-69851805: G***; kibuzzard-69851805
kibuzzard-69851812: G***; kibuzzard-69851812
kibuzzard-69861606: G***; kibuzzard-69861606

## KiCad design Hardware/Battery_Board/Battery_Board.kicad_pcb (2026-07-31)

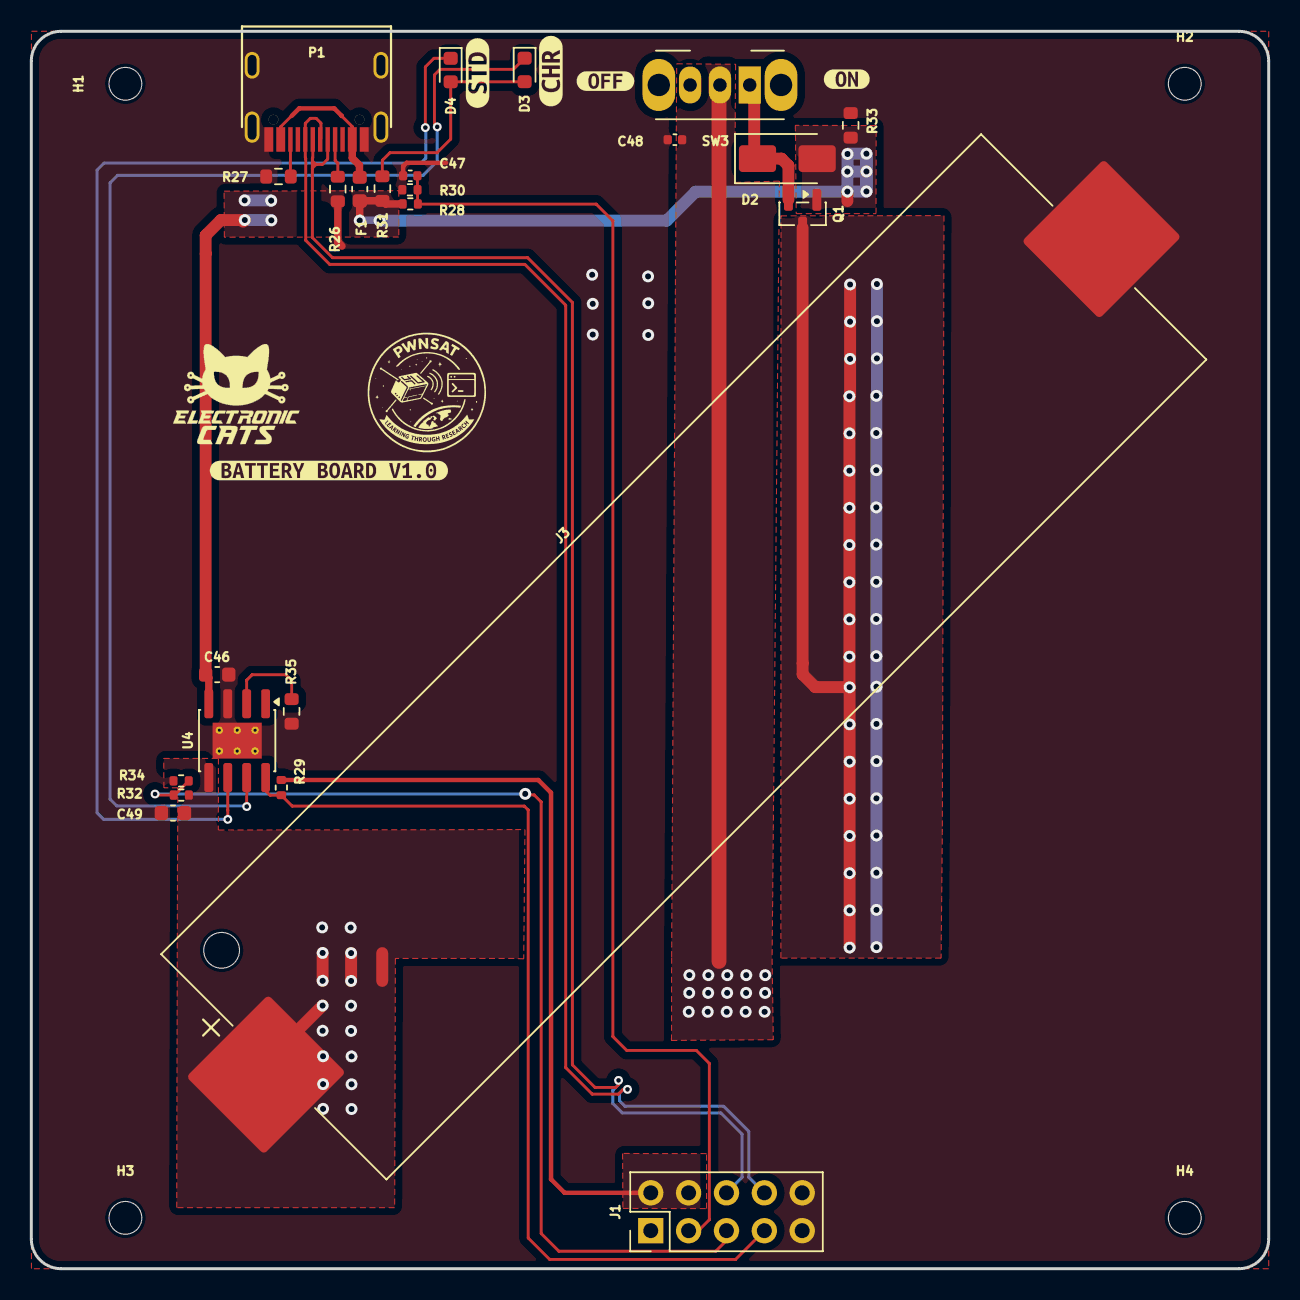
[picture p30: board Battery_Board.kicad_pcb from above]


Board: 2 copper layers, 83.0 x 83.0 mm, 35 parts (2 on the bottom side), 18 nets.

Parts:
C46, C49: 10uF; C_0603_1608Metric
C47: 100nF; C_0402_1005Metric
C48: 10uF; C_0402_1005Metric
D2: SS34; D_SMA
D3, D4: LED; LED_0603_1608Metric
F1: 2A; Fuse_0603_1608Metric
H1, H2, H3, H4: MountingHole; MountingHole_2.2mm_M2
J1: Source; PinHeader_2x05_P2.54mm_Vertical
J3: Battery; BatteryHolder_Keystone_1042_1x18650
P1: USB_C_Plug_USB2.0; C393939
Q1: DMG3415U-7; SOT-23
R26, R27: 5k1; R_0603_1608Metric
R28, R29, R34: 10K; R_0402_1005Metric
R30: 18k; R_0402_1005Metric
R31, R35: 2K; R_0603_1608Metric
R32: 10.7K; R_0402_1005Metric
R33: 100K; R_0603_1608Metric
SW3: ON; SW_Slide_SPDT_Angled_CK_OS102011MA1Q
U4: TP4056; SOIC-8-1EP_3.9x4.9mm_P1.27mm_EP2.41x3.3mm_ThermalVias
kibuzzard-698511AF: G***; kibuzzard-698511AF
kibuzzard-698511C2: G***; kibuzzard-698511C2
kibuzzard-6985125C: G***; kibuzzard-6985125C
kibuzzard-69851248, kibuzzard-69851248#2: G***; kibuzzard-69851248
kibuzzard-69851454: G***; kibuzzard-69851454
kibuzzard-69851473: G***; kibuzzard-69851473

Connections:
+3.3V: J1.2, J1.4, R29.1
+BATT: C49.1, J3.1, Q1.3 (D), R32.1, U4.5 (BAT)
/Batt_Connector/2_DN: J1.6, P1.A7 (D-)
/Batt_Connector/2_DP: J1.8, P1.A6 (D+)
/Batt_Connector/Battery: J1.5, R32.2, R34.1
/Batt_Connector/Enable: J1.7, R29.2, U4.8 (CE)
/Batt_Connector/USB_DET: C47.1, J1.3, R28.1, R30.1
GND: C46.1, C47.2, C48.2, C49.2, J1.9, J1.10, J3.2, P1.A1 (GND), P1.S1 (SHIELD), R26.1, R27.1, R30.2, R33.2, R34.2, R35.2, U4.3 (GND), U4.9 (EPAD)
unnamed: D2.1 (K), Q1.2 (S), SW3.1 (A)
unnamed: D3.2 (A), D4.2 (A), R31.2
unnamed: D3.1 (K), U4.7 (~CHRG)
unnamed: D4.1 (K), U4.6 (~STDBY)
unnamed: F1.1, P1.A4 (VBUS)
unnamed: P1.A5 (CC), R26.2
unnamed: P1.B5 (VCONN), R27.2
unnamed: R35.1, U4.2 (PROG)
VBUS: C46.2, D2.2 (A), F1.2, Q1.1 (G), R28.2, R31.1, R33.1, U4.4 (V_{CC})
VCC: C48.1, J1.1, SW3.2 (B)

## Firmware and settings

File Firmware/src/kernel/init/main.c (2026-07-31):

// SPDX-License-Identifier: GPL-2.0-only
/*
 *  linux/init/main.c
 *
 *  Copyright (C) 1991, 1992  Linus Torvalds
 *
 *  GK 2/5/95  -  Changed to support mounting root fs via NFS
 *  Added initrd & change_root: Werner Almesberger & Hans Lermen, Feb '96
 *  Moan early if gcc is old, avoiding bogus kernels - Paul Gortmaker, May '96
 *  Simplified starting of init:  Michael A. Griffith <grif@acm.org>
 */

#define DEBUG		/* Enable initcall_debug */

#include <linux/types.h>
#include <linux/extable.h>
#include <linux/module.h>
#include <linux/proc_fs.h>
#include <linux/binfmts.h>
#include <linux/kernel.h>
#include <linux/syscalls.h>
#include <linux/stackprotector.h>
#include <linux/string.h>
#include <linux/ctype.h>
#include <linux/delay.h>
#include <linux/ioport.h>
#include <linux/init.h>
#include <linux/initrd.h>
#include <linux/memblock.h>
#include <linux/acpi.h>
#include <linux/bootconfig.h>
#include <linux/console.h>
#include <linux/nmi.h>
#include <linux/percpu.h>
#include <linux/kmod.h>
#include <linux/kprobes.h>
#include <linux/vmalloc.h>
#include <linux/kernel_stat.h>
#include <linux/start_kernel.h>
#include <linux/security.h>
#include <linux/smp.h>
#include <linux/profile.h>
#include <linux/kfence.h>
#include <linux/rcupdate.h>
#include <linux/moduleparam.h>
#include <linux/kallsyms.h>
#include <linux/writeback.h>
#include <linux/cpu.h>
#include <linux/cpuset.h>
#include <linux/cgroup.h>
#include <linux/efi.h>
#include <linux/tick.h>
#include <linux/sched/isolation.h>
#include <linux/interrupt.h>
#include <linux/taskstats_kern.h>
#include <linux/delayacct.h>
#include <linux/unistd.h>
#include <linux/utsname.h>
#include <linux/rmap.h>
#include <linux/mempolicy.h>
#include <linux/key.h>
#include <linux/buffer_head.h>
#include <linux/page_ext.h>
#include <linux/debug_locks.h>
#include <linux/debugobjects.h>
#include <linux/lockdep.h>
#include <linux/kmemleak.h>
#include <linux/padata.h>
#include <linux/pid_namespace.h>
#include <linux/device/driver.h>
#include <linux/kthread.h>
#include <linux/sched.h>
#include <linux/sched/init.h>
#include <linux/signal.h>
#include <linux/idr.h>
#include <linux/kgdb.h>
#include <linux/ftrace.h>
#include <linux/async.h>
#include <linux/sfi.h>
#include <linux/shmem_fs.h>
#include <linux/slab.h>
#include <linux/perf_event.h>
#include <linux/ptrace.h>
#include <linux/pti.h>
#include <linux/blkdev.h>
#include <linux/elevator.h>
#include <linux/sched/clock.h>
#include <linux/sched/task.h>
#include <linux/sched/task_stack.h>
#include <linux/context_tracking.h>
#include <linux/random.h>
#include <linux/list.h>
#include <linux/integrity.h>
#include <linux/proc_ns.h>
#include <linux/io.h>
#include <linux/cache.h>
#include <linux/rodata_test.h>
#include <linux/jump_label.h>
#include <linux/mem_encrypt.h>
#include <linux/kcsan.h>
#include <linux/init_syscalls.h>
#include <linux/stackdepot.h>

#include <asm/io.h>
#include <asm/bugs.h>
#include <asm/setup.h>
#include <asm/sections.h>
#include <asm/cacheflush.h>

#define CREATE_TRACE_POINTS
#include <trace/events/initcall.h>

#include <kunit/test.h>

static int kernel_init(void *);

extern void init_IRQ(void);
extern void radix_tree_init(void);

/*
 * Debug helper: via this flag we know that we are in 'early bootup code'
 * where only the boot processor is running with IRQ disabled.  This means
 * two things - IRQ must not be enabled before the flag is cleared and some
 * operations which are not allowed with IRQ disabled are allowed while the
 * flag is set.
 */
bool early_boot_irqs_disabled __read_mostly;

enum system_states system_state __read_mostly;
EXPORT_SYMBOL(system_state);

/*
 * Boot command-line arguments
 */
#define MAX_INIT_ARGS CONFIG_INIT_ENV_ARG_LIMIT
#define MAX_INIT_ENVS CONFIG_INIT_ENV_ARG_LIMIT

extern void time_init(void);
/* Default late time init is NULL. archs can override this later. */
void (*__initdata late_time_init)(void);

/* Untouched command line saved by arch-specific code. */
char __initdata boot_command_line[COMMAND_LINE_SIZE];
/* Untouched saved command line (eg. for /proc) */
char *saved_command_line;
/* Command line for parameter parsing */
static char *static_command_line;
/* Untouched extra command line */
static char *extra_command_line;
/* Extra init arguments */
static char *extra_init_args;

#ifdef CONFIG_BOOT_CONFIG
/* Is bootconfig on command line? */
static bool bootconfig_found;
static bool initargs_found;
#else
# define bootconfig_found false
# define initargs_found false
#endif

static char *execute_command;
static char *ramdisk_execute_command = "/init";

/*
 * Used to generate warnings if static_key manipulation functions are used
 * before jump_label_init is called.
 */
bool static_key_initialized __read_mostly;
EXPORT_SYMBOL_GPL(static_key_initialized);

/*
 * If set, this is an indication to the drivers that reset the underlying
 * device before going ahead with the initialization otherwise driver might
 * rely on the BIOS and skip the reset operation.
 *
 * This is useful if kernel is booting in an unreliable environment.
 * For ex. kdump situation where previous kernel has crashed, BIOS has been
 * skipped and devices will be in unknown state.
 */
unsigned int reset_devices;
EXPORT_SYMBOL(reset_devices);

static int __init set_reset_devices(char *str)
{
	reset_devices = 1;
	return 1;
}

__setup("reset_devices", set_reset_devices);

static const char *argv_init[MAX_INIT_ARGS+2] = { "init", NULL, };
const char *envp_init[MAX_INIT_ENVS+2] = { "HOME=/", "TERM=linux", NULL, };
static const char *panic_later, *panic_param;

extern const struct obs_kernel_param __setup_start[], __setup_end[];

static bool __init obsolete_checksetup(char *line)
{
	const struct obs_kernel_param *p;
	bool had_early_param = false;

	p = __setup_start;
	do {
		int n = strlen(p->str);
		if (parameqn(line, p->str, n)) {
			if (p->early) {
				/* Already done in parse_early_param?
				 * (Needs exact match on param part).
				 * Keep iterating, as we can have early
				 * params and __setups of same names 8( */
				if (line[n] == '\0' || line[n] == '=')
					had_early_param = true;
			} else if (!p->setup_func) {
				pr_warn("Parameter %s is obsolete, ignored\n",
					p->str);
				return true;
			} else if (p->setup_func(line + n))
				return true;
		}
		p++;
	} while (p < __setup_end);

	return had_early_param;
}

/*
 * This should be approx 2 Bo*oMips to start (note initial shift), and will
 * still work even if initially too large, it will just take slightly longer
 */
unsigned long loops_per_jiffy = (1<<12);
EXPORT_SYMBOL(loops_per_jiffy);

static int __init debug_kernel(char *str)
{
	console_loglevel = CONSOLE_LOGLEVEL_DEBUG;
	return 0;
}

static int __init quiet_kernel(char *str)
{
	console_loglevel = CONSOLE_LOGLEVEL_QUIET;
	return 0;
}

early_param("debug", debug_kernel);
early_param("quiet", quiet_kernel);

static int __init loglevel(char *str)
{
	int newlevel;

	/*
	 * Only update loglevel value when a correct setting was passed,
	 * to prevent blind crashes (when loglevel being set to 0) that
	 * are quite hard to debug
	 */
	if (get_option(&str, &newlevel)) {
		console_loglevel = newlevel;
		return 0;
	}

	return -EINVAL;
}

early_param("loglevel", loglevel);

#ifdef CONFIG_BLK_DEV_INITRD
static void * __init get_boot_config_from_initrd(u32 *_size, u32 *_csum)
{
	u32 size, csum;
	char *data;
	u32 *hdr;
	int i;

	if (!initrd_end)
		return NULL;

	data = (char *)initrd_end - BOOTCONFIG_MAGIC_LEN;
	/*
	 * Since Grub may align the size of initrd to 4, we must
	 * check the preceding 3 bytes as well.
	 */
	for (i = 0; i < 4; i++) {
		if (!memcmp(data, BOOTCONFIG_MAGIC, BOOTCONFIG_MAGIC_LEN))
			goto found;
		data--;
	}
	return NULL;

found:
	hdr = (u32 *)(data - 8);
	size = le32_to_cpu(hdr[0]);
	csum = le32_to_cpu(hdr[1]);

	data = ((void *)hdr) - size;
	if ((unsigned long)data < initrd_start) {
		pr_err("bootconfig size %d is greater than initrd size %ld\n",
			size, initrd_end - initrd_start);
		return NULL;
	}

	/* Remove bootconfig from initramfs/initrd */
	initrd_end = (unsigned long)data;
	if (_size)
		*_size = size;
	if (_csum)
		*_csum = csum;

	return data;
}
#else
static void * __init get_boot_config_from_initrd(u32 *_size, u32 *_csum)
{
	return NULL;
}
#endif

#ifdef CONFIG_BOOT_CONFIG

static char xbc_namebuf[XBC_KEYLEN_MAX] __initdata;

#define rest(dst, end) ((end) > (dst) ? (end) - (dst) : 0)

static int __init xbc_snprint_cmdline(char *buf, size_t size,
				      struct xbc_node *root)
{
	struct xbc_node *knode, *vnode;
	char *end = buf + size;
	const char *val;
	int ret;

	xbc_node_for_each_key_value(root, knode, val) {
		ret = xbc_node_compose_key_after(root, knode,
					xbc_namebuf, XBC_KEYLEN_MAX);
		if (ret < 0)
			return ret;

		vnode = xbc_node_get_child(knode);
		if (!vnode) {
			ret = snprintf(buf, rest(buf, end), "%s ", xbc_namebuf);
			if (ret < 0)
				return ret;
			buf += ret;
			continue;
		}
		xbc_array_for_each_value(vnode, val) {
			ret = snprintf(buf, rest(buf, end), "%s=\"%s\" ",
				       xbc_namebuf, val);
			if (ret < 0)
				return ret;
			buf += ret;
		}
	}

	return buf - (end - size);
}
#undef rest

/* Make an extra command line under given key word */
static char * __init xbc_make_cmdline(const char *key)
{
	struct xbc_node *root;
	char *new_cmdline;
	int ret, len = 0;

	root = xbc_find_node(key);
	if (!root)
		return NULL;

	/* Count required buffer size */
	len = xbc_snprint_cmdline(NULL, 0, root);
	if (len <= 0)
		return NULL;

	new_cmdline = memblock_alloc(len + 1, SMP_CACHE_BYTES);
	if (!new_cmdline) {
		pr_err("Failed to allocate memory for extra kernel cmdline.\n");
		return NULL;
	}

	ret = xbc_snprint_cmdline(new_cmdline, len + 1, root);
	if (ret < 0 || ret > len) {
		pr_err("Failed to print extra kernel cmdline.\n");
		memblock_free(__pa(new_cmdline), len + 1);
		return NULL;
	}

	return new_cmdline;
}

static int __init bootconfig_params(char *param, char *val,
				    const char *unused, void *arg)
{
	if (strcmp(param, "bootconfig") == 0) {
		bootconfig_found = true;
	}
	return 0;
}

static void __init setup_boot_config(const char *cmdline)
{
	static char tmp_cmdline[COMMAND_LINE_SIZE] __initdata;
	const char *msg;
	int pos;
	u32 size, csum;
	char *data, *copy, *err;
	int ret;

	/* Cut out the bootconfig data even if we have no bootconfig option */
	data = get_boot_config_from_initrd(&size, &csum);

	strlcpy(tmp_cmdline, boot_command_line, COMMAND_LINE_SIZE);
	err = parse_args("bootconfig", tmp_cmdline, NULL, 0, 0, 0, NULL,
			 bootconfig_params);

	if (IS_ERR(err) || !bootconfig_found)
		return;

	/* parse_args() stops at '--' and returns an address */
	if (err)
		initargs_found = true;

	if (!data) {
		pr_err("'bootconfig' found on command line, but no bootconfig found\n");
		return;
	}

	if (size >= XBC_DATA_MAX) {
		pr_err("bootconfig size %d greater than max size %d\n",
			size, XBC_DATA_MAX);
		return;
	}

	if (xbc_calc_checksum(data, size) != csum) {
		pr_err("bootconfig checksum failed\n");
		return;
	}

	copy = memblock_alloc(size + 1, SMP_CACHE_BYTES);
	if (!copy) {
		pr_err("Failed to allocate memory for bootconfig\n");
		return;
	}

	memcpy(copy, data, size);
	copy[size] = '\0';

	ret = xbc_init(copy, &msg, &pos);
	if (ret < 0) {
		if (pos < 0)
			pr_err("Failed to init bootconfig: %s.\n", msg);
		else
			pr_err("Failed to parse bootconfig: %s at %d.\n",
				msg, pos);
	} else {
		pr_info("Load bootconfig: %d bytes %d nodes\n", size, ret);
		/* keys starting with "kernel." are passed via cmdline */
		extra_command_line = xbc_make_cmdline("kernel");
		/* Also, "init." keys are init arguments */
		extra_init_args = xbc_make_cmdline("init");
	}
	return;
}

#else

static void __init setup_boot_config(const char *cmdline)
{
	/* Remove bootconfig data from initrd */
	get_boot_config_from_initrd(NULL, NULL);
}

static int __init warn_bootconfig(char *str)
{
	pr_warn("WARNING: 'bootconfig' found on the kernel command line but CONFIG_BOOT_CONFIG is not set.\n");
	return 0;
}
early_param("bootconfig", warn_bootconfig);

#endif

/* Change NUL term back to "=", to make "param" the whole string. */
static void __init repair_env_string(char *param, char *val)
{
	if (val) {
		/* param=val or param="val"? */
		if (val == param+strlen(param)+1)
			val[-1] = '=';
		else if (val == param+strlen(param)+2) {
			val[-2] = '=';
			memmove(val-1, val, strlen(val)+1);
		} else
			BUG();
	}
}

/* Anything after -- gets handed straight to init. */
static int __init set_init_arg(char *param, char *val,
			       const char *unused, void *arg)
{
	unsigned int i;

	if (panic_later)
		return 0;

	repair_env_string(param, val);

	for (i = 0; argv_init[i]; i++) {
		if (i == MAX_INIT_ARGS) {
			panic_later = "init";
			panic_param = param;
			return 0;
		}
	}
	argv_init[i] = param;
	return 0;
}

/*
 * Unknown boot options get handed to init, unless they look like
 * unused parameters (modprobe will find them in /proc/cmdline).
 */
static int __init unknown_bootoption(char *param, char *val,
				     const char *unused, void *arg)
{
	size_t len = strlen(param);

	repair_env_string(param, val);

	/* Handle obsolete-style parameters */
	if (obsolete_checksetup(param))
		return 0;

	/* Unused module parameter. */
	if (strnchr(param, len, '.'))
		return 0;

	if (panic_later)
		return 0;

	if (val) {
		/* Environment option */
		unsigned int i;
		for (i = 0; envp_init[i]; i++) {
			if (i == MAX_INIT_ENVS) {
				panic_later = "env";
				panic_param = param;
			}
			if (!strncmp(param, envp_init[i], len+1))
				break;
		}
		envp_init[i] = param;
	} else {
		/* Command line option */
		unsigned int i;
		for (i = 0; argv_init[i]; i++) {
			if (i == MAX_INIT_ARGS) {
				panic_later = "init";
				panic_param = param;
			}
		}
		argv_init[i] = param;
	}
	return 0;
}

static int __init init_setup(char *str)
{
	unsigned int i;

	execute_command = str;
	/*
	 * In case LILO is going to boot us with default command line,
	 * it prepends "auto" before the whole cmdline which makes
	 * the shell think it should execute a script with such name.
	 * So we ignore all arguments entered _before_ init=... [MJ]
	 */
	for (i = 1; i < MAX_INIT_ARGS; i++)
		argv_init[i] = NULL;
	return 1;
}
__setup("init=", init_setup);

static int __init rdinit_setup(char *str)
{
	unsigned int i;

	ramdisk_execute_command = str;
	/* See "auto" comment in init_setup */
	for (i = 1; i < MAX_INIT_ARGS; i++)
		argv_init[i] = NULL;
	return 1;
}
__setup("rdinit=", rdinit_setup);

#ifndef CONFIG_SMP
static const unsigned int setup_max_cpus = NR_CPUS;
static inline void setup_nr_cpu_ids(void) { }
static inline void smp_prepare_cpus(unsigned int maxcpus) { }
#endif

/*
 * We need to store the untouched command line for future reference.
 * We also need to store the touched command line since the parameter
 * parsing is performed in place, and we should allow a component to
 * store reference of name/value for future reference.
 */
static void __init setup_command_line(char *command_line)
{
	size_t len, xlen = 0, ilen = 0;

	if (extra_command_line)
		xlen = strlen(extra_command_line);
	if (extra_init_args)
		ilen = strlen(extra_init_args) + 4; /* for " -- " */

	len = xlen + strlen(boot_command_line) + 1;

	saved_command_line = memblock_alloc(len + ilen, SMP_CACHE_BYTES);
	if (!saved_command_line)
		panic("%s: Failed to allocate %zu bytes\n", __func__, len + ilen);

	static_command_line = memblock_alloc(len, SMP_CACHE_BYTES);
	if (!static_command_line)
		panic("%s: Failed to allocate %zu bytes\n", __func__, len);

	if (xlen) {
		/*
		 * We have to put extra_command_line before boot command
		 * lines because there could be dashes (separator of init
		 * command line) in the command lines.
		 */
		strcpy(saved_command_line, extra_command_line);
		strcpy(static_command_line, extra_command_line);
	}
	strcpy(saved_command_line + xlen, boot_command_line);
	strcpy(static_command_line + xlen, command_line);

	if (ilen) {
		/*
		 * Append supplemental init boot args to saved_command_line
		 * so that user can check what command line options passed
		 * to init.
		 */
		len = strlen(saved_command_line);
		if (initargs_found) {
			saved_command_line[len++] = ' ';
		} else {
			strcpy(saved_command_line + len, " -- ");
			len += 4;
		}

		strcpy(saved_command_line + len, extra_init_args);
	}
}

/*
 * We need to finalize in a non-__init function or else race conditions
 * between the root thread and the init thread may cause start_kernel to
 * be reaped by free_initmem before the root thread has proceeded to
 * cpu_idle.
 *
 * gcc-3.4 accidentally inlines this function, so use noinline.
 */

static __initdata DECLARE_COMPLETION(kthreadd_done);

noinline void __ref rest_init(void)
{
	struct task_struct *tsk;
	int pid;

	rcu_scheduler_starting();
	/*
	 * We need to spawn init first so that it obtains pid 1, however
	 * the init task will end up wanting to create kthreads, which, if
	 * we schedule it before we create kthreadd, will OOPS.
	 */
	pid = kernel_thread(kernel_init, NULL, CLONE_FS);
	/*
	 * Pin init on the boot CPU. Task migration is not properly working
	 * until sched_init_smp() has been run. It will set the allowed
	 * CPUs for init to the non isolated CPUs.
	 */
	rcu_read_lock();
	tsk = find_task_by_pid_ns(pid, &init_pid_ns);
	set_cpus_allowed_ptr(tsk, cpumask_of(smp_processor_id()));
	rcu_read_unlock();

	numa_default_policy();
	pid = kernel_thread(kthreadd, NULL, CLONE_FS | CLONE_FILES);
	rcu_read_lock();
	kthreadd_task = find_task_by_pid_ns(pid, &init_pid_ns);
	rcu_read_unlock();

	/*
	 * Enable might_sleep() and smp_processor_id() checks.
	 * They cannot be enabled earlier because with CONFIG_PREEMPTION=y
	 * kernel_thread() would trigger might_sleep() splats. With
	 * CONFIG_PREEMPT_VOLUNTARY=y the init task might have scheduled
	 * already, but it's stuck on the kthreadd_done completion.
	 */
	system_state = SYSTEM_SCHEDULING;

	complete(&kthreadd_done);

	/*
	 * The boot idle thread must execute schedule()
	 * at least once to get things moving:
	 */
	schedule_preempt_disabled();
	/* Call into cpu_idle with preempt disabled */
	cpu_startup_entry(CPUHP_ONLINE);
}

/* Check for early params. */
static int __init do_early_param(char *param, char *val,
				 const char *unused, void *arg)
{
	const struct obs_kernel_param *p;

	for (p = __setup_start; p < __setup_end; p++) {
		if ((p->early && parameq(param, p->str)) ||
		    (strcmp(param, "console") == 0 &&
		     strcmp(p->str, "earlycon") == 0)
		) {
			if (p->setup_func(val) != 0)
				pr_warn("Malformed early option '%s'\n", param);
		}
	}
	/* We accept everything at this stage. */
	return 0;
}

void __init parse_early_options(char *cmdline)
{
	parse_args("early options", cmdline, NULL, 0, 0, 0, NULL,
		   do_early_param);
}

/* Arch code calls this early on, or if not, just before other parsing. */
void __init parse_early_param(void)
{
	static int done __initdata;
	static char tmp_cmdline[COMMAND_LINE_SIZE] __initdata;

	if (done)
		return;

	/* All fall through to do_early_param. */
	strlcpy(tmp_cmdline, boot_command_line, COMMAND_LINE_SIZE);
	parse_early_options(tmp_cmdline);
	done = 1;
}

void __init __weak arch_post_acpi_subsys_init(void) { }

void __init __weak smp_setup_processor_id(void)
{
}

# if THREAD_SIZE >= PAGE_SIZE
void __init __weak thread_stack_cache_init(void)
{
}
#endif

void __init __weak mem_encrypt_init(void) { }

void __init __weak poking_init(void) { }

void __init __weak pgtable_cache_init(void) { }

bool initcall_debug;
core_param(initcall_debug, initcall_debug, bool, 0644);

#ifdef TRACEPOINTS_ENABLED
static void __init initcall_debug_enable(void);
#else
static inline void initcall_debug_enable(void)
{
}
#endif

/* Report memory auto-initialization states for this boot. */
static void __init report_meminit(void)
{
	const char *stack;

	if (IS_ENABLED(CONFIG_INIT_STACK_ALL_PATTERN))
		stack = "all(pattern)";
	else if (IS_ENABLED(CONFIG_INIT_STACK_ALL_ZERO))
		stack = "all(zero)";
	else if (IS_ENABLED(CONFIG_GCC_PLUGIN_STRUCTLEAK_BYREF_ALL))
		stack = "byref_all(zero)";
	else if (IS_ENABLED(CONFIG_GCC_PLUGIN_STRUCTLEAK_BYREF))
		stack = "byref(zero)";
	else if (IS_ENABLED(CONFIG_GCC_PLUGIN_STRUCTLEAK_USER))
		stack = "__user(zero)";
	else
		stack = "off";

	pr_info("mem auto-init: stack:%s, heap alloc:%s, heap free:%s\n",
		stack, want_init_on_alloc(GFP_KERNEL) ? "on" : "off",
		want_init_on_free() ? "on" : "off");
	if (want_init_on_free())
		pr_info("mem auto-init: clearing system memory may take some time...\n");
}

/*
 * Set up kernel memory allocators
 */
static void __init mm_init(void)
{
	/*
	 * page_ext requires contiguous pages,
	 * bigger than MAX_ORDER unless SPARSEMEM.
	 */
	page_ext_init_flatmem();
	init_mem_debugging_and_hardening();
	kfence_alloc_pool();
	report_meminit();
	stack_depot_init();
	mem_init();
	/* page_owner must be initialized after buddy is ready */
	page_ext_init_flatmem_late();
	kmem_cache_init();
	kmemleak_init();
	pgtable_init();
	debug_objects_mem_init();
	vmalloc_init();
	ioremap_huge_init();
	/* Should be run before the first non-init thread is created */
	init_espfix_bsp();
	/* Should be run after espfix64 is set up. */
	pti_init();
}

void __init __weak arch_call_rest_init(void)
{
	rest_init();
}

asmlinkage __visible void __init __no_sanitize_address start_kernel(void)
{
	char *command_line;
	char *after_dashes;

#if defined(CONFIG_DEBUG_LL) && defined(CONFIG_ARM)
	/* CubeSat boot-debug milestone: C entry reached */
	{
		extern void printascii(const char *);
		printascii("start_kernel\n");
	}
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

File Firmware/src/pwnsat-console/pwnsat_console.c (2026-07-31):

/* PWNSAT console -- "Black Hat Arsenal Edition" banner/menu, ported from the
 * FlatSat serial console (spacecan.cpp: scPrintBanner/scPrintMenu). FlatSat
 * runs this bare-metal over USB CDC; on PWNCUBE the USB gadget console is
 * owned by Linux (ttyGS0), so this is a userspace client instead of MCU
 * code -- same rpmsg-backed data (sensor_test/radio_test), new front end.
 *
 * Launched as the ttyGS0 respawn entry (see rootfs/skeleton/etc/inittab),
 * replacing the raw `/bin/sh` PWNCUBE had before. Menu option 3 (Debug
 * Shell) is the escape hatch back to a real shell for tools like
 * pwncube_console.py that expect one waiting on the other end.
 */
#include <stdio.h>
#include <stdlib.h>
#include <string.h>
#include <unistd.h>
#include <termios.h>
#include <sys/select.h>

#include "spacecan_sim.h"

#define ANSI_RESET   "\x1b[0m"
#define ANSI_GREEN   "\x1b[32m"
#define ANSI_CYAN    "\x1b[36m"
#define ANSI_YELLOW  "\x1b[33m"
#define ANSI_MAGENTA "\x1b[35m"

static struct termios orig_termios;

static void restore_termios(void) {
    tcsetattr(STDIN_FILENO, TCSANOW, &orig_termios);
}

static void set_raw_mode(void) {
    struct termios raw;
    tcgetattr(STDIN_FILENO, &orig_termios);
    raw = orig_termios;
    raw.c_lflag &= ~(ICANON | ECHO);
    /* Force \n -> \r\n translation on output for this tty. termios output
     * settings belong to the tty device, not to our process, so this also
     * fixes plain-\n output from subprocesses we spawn (sensor_test,
     * radio_test) without touching their source. Without this, the
     * "generic" usbserial driver on the far end (its own dmesg warning:
     * "only for testing and one-off prototypes") doesn't reliably do this
     * translation on its own -- output comes out staircased/torn. */
    raw.c_oflag |= OPOST | ONLCR;
    raw.c_cc[VMIN] = 0;
    raw.c_cc[VTIME] = 0;
    tcsetattr(STDIN_FILENO, TCSANOW, &raw);
}

static void print_banner(void) {
    printf(ANSI_GREEN
        "              \\             /\n"
        "               \\           /\n"
        "                +---------+\n"
        "                |         |\n"
        "                | [ ][ ]  |\n"
        "                |         |\n"
        "                +---------+\n"
        "               /           \\\n"
        "              /             \\\n"
        "\n"
        "              P W N S A T\n"
        "       --  BLACK HAT ARSENAL EDITION  --\n"
        ANSI_RESET);
}

/* Matches FlatSat's scPrintMenu(), which always prints the banner too --
 * every reprint (initial, M, idle refresh, back from a submenu) shows the
 * full art, not just the menu lines. */
static void print_menu(void) {
    print_banner();
    printf("\n");
    printf("==================================================\n");
    printf("PWNSAT CONSOLE: Press the number to select.\n");
    printf("  1) Sensor / Telemetry Dashboard\n");
    printf("  2) SpaceCAN Bus Console\n");
    printf("  3) Debug Shell\n");
    printf("  4) Exit console (quiet mode)\n");
    printf("Press M anytime to return here.\n");
    printf("==================================================\n");
}

/* Reads one key with a timeout (seconds). Returns 0 on timeout, -1 on EOF,
 * else the key. Lets the dashboard refresh while staying responsive. */
static int read_key_timeout(int timeout_s) {
    fd_set fds;
    struct timeval tv;
    FD_ZERO(&fds);
    FD_SET(STDIN_FILENO, &fds);
    tv.tv_sec = timeout_s;
    tv.tv_usec = 0;
    int rv = select(STDIN_FILENO + 1, &fds, NULL, NULL, &tv);
    if (rv <= 0) return 0;
    unsigned char c;
    ssize_t n = read(STDIN_FILENO, &c, 1);
    if (n <= 0) return -1;
    return c;
}

static void read_uptime(unsigned long *hh, unsigned long *mm, unsigned long *ss,
                         unsigned long *total_ms) {
    FILE *f = fopen("/proc/uptime", "r");
    double up = 0.0;
    if (f) {
        if (fscanf(f, "%lf", &up) != 1) up = 0.0;
        fclose(f);
    }
    unsigned long total_s = (unsigned long)up;
    *total_ms = (unsigned long)(up * 1000.0);
    *hh = total_s / 3600UL;
    *mm = (total_s % 3600UL) / 60UL;
    *ss = total_s % 60UL;
}

/* Ported from FlatSat's printSystemStatusDashboard() (worker.cpp) -- same
 * sections/labels, sourced from sensor_test/radio_test over rpmsg instead
 * of direct hardware reads. GPS/NAV now backed by the real NEO-6M driver
 * (Etapa 5, gps_nmea.c/.h on the MCU side) via `radio_test gps_status` --
 * a synchronous local rpmsg query, same pattern as `sensor_test all`
 * below, no SPP/RF round trip involved. */
static void print_system_status_dashboard(void) {
    unsigned long hh, mm, ss, total_ms;
    read_uptime(&hh, &mm, &ss, &total_ms);

    printf("==================================================\n");
    printf("--- SYSTEM STATUS DASHBOARD ---\n");
    printf("Satellite Uptime:    %02lu:%02lu:%02lu (%lu ms)\n", hh, mm, ss, total_ms);
    printf("\n");
    printf("--- RADIO SUBSYSTEM ---\n");
    printf("Downlink:            916 MHz\n"); /* mission.h DOWNLINK_FREQ */
    printf("Uplink:              918 MHz\n"); /* mission.h UPLINK_FREQ */
    printf("\n");
    printf("--- GPS / NAV ---\n");
    {
        int override_active = 0, uart_ok = 0, fix_valid = 0, sats = 0;
        float lat = 0.0f, lon = 0.0f, alt = 0.0f;
        int got = 0;
        FILE *gp = popen("radio_test gps_status 2>/dev/null", "r");
        if (gp) {
            char gline[256];
            while (fgets(gline, sizeof(gline), gp)) {
                if (sscanf(gline,
                           "gps_status: override=%d uart_ok=%d fix=%d sats=%d "
                           "lat=%f lon=%f alt=%f",
                           &override_active, &uart_ok, &fix_valid, &sats,
                           &lat, &lon, &alt) == 7) {
                    got = 1;
                }
            }
            pclose(gp);
        }
        if (!got) {
            printf("(no response from gps_status -- rpmsg/MCU not reachable)\n");
        } else if (!uart_ok) {
            printf("Real receiver:       not connected (UART0 silent)\n");
        } else if (!fix_valid) {
            printf("Real receiver:       connected, no satellite fix yet\n");
        } else {
            printf("Real receiver:       fix OK, %d satellite(s)\n", sats);
            printf("  Lat / Lon:         %.6f / %.6f\n", lat, lon);
            printf("  Altitude:          %.2f m\n", alt);
        }
        printf("Debug override (GPS_OVERRIDE): %s\n", override_active ? "ACTIVE" : "inactive");
    }
    printf("\n");
    printf("--- SENSOR TELEMETRY ---\n");
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

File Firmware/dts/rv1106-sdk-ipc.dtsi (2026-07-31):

// SPDX-License-Identifier: (GPL-2.0+ OR MIT)
/*
 * Copyright (c) 2022 Rockchip Electronics Co., Ltd.
 */
#include "rv1106-amp.dtsi"

/ {
	chosen {
		bootargs = "earlycon=uart8250,mmio32,0xff4c0000 console=ttyFIQ0 root=/dev/mmcblk1p7 rootwait snd_soc_core.prealloc_buffer_size_kbytes=16 coherent_pool=0";
	};

	acodec_sound: acodec-sound {
		compatible = "simple-audio-card";
		simple-audio-card,name = "rv-acodec";
		simple-audio-card,format = "i2s";
		simple-audio-card,mclk-fs = <256>;
		simple-audio-card,cpu {
			sound-dai = <&i2s0_8ch>;
		};
		simple-audio-card,codec {
			sound-dai = <&acodec>;
		};
	};

	vcc_1v8: vcc-1v8 {
		compatible = "regulator-fixed";
		regulator-name = "vcc_1v8";
		regulator-always-on;
		regulator-boot-on;
		regulator-min-microvolt = <1800000>;
		regulator-max-microvolt = <1800000>;
	};

	vcc_3v3: vcc-3v3 {
		compatible = "regulator-fixed";
		regulator-name = "vcc_3v3";
		regulator-always-on;
		regulator-boot-on;
		regulator-min-microvolt = <3300000>;
		regulator-max-microvolt = <3300000>;
	};

	vdd_arm: vdd-arm {
		compatible = "regulator-fixed";
		regulator-name = "vdd_arm";
		regulator-min-microvolt = <900000>;
		regulator-max-microvolt = <900000>;
		regulator-always-on;
		regulator-boot-on;
	};
	leds: leds {
		compatible = "gpio-leds";
		work_led: work{
			gpios = <&gpio3 RK_PC6 GPIO_ACTIVE_HIGH>;
			linux,default-trigger = "activity";
			default-state = "on";
		};	
	};

};

/***************************** AUDIO ********************************/
&i2s0_8ch {
	#sound-dai-cells = <0>;
	status = "okay";
};

&acodec {
	#sound-dai-cells = <0>;
	pa-ctl-gpios = <&gpio1 RK_PA1 GPIO_ACTIVE_HIGH>;
	status = "okay";
};
/***************************** CPU ********************************/
&cpu0 {
	cpu-supply = <&vdd_arm>;
};

/***************************** ADC ********************************/
/* SARADC (SoC successive-approximation ADC) unused — disabled so it does not
 * register an IIO device (otherwise it takes iio:device0 before the BME280). */
&saradc {
	status = "disabled";
	vref-supply = <&vcc_1v8>;
};

&tsadc {
	status = "okay";
};

/***************************** CSI ********************************/
&csi2_dphy_hw {
	status = "okay";
};

&csi2_dphy0 {
	status = "okay";

	ports {
		#address-cells = <1>;
		#size-cells = <0>;

		port@0 {
			reg = <0>;
			#address-cells = <1>;
			#size-cells = <0>;

			csi_dphy_input0: endpoint@0 {
				reg = <0>;
				remote-endpoint = <&sc3336_out>;
				data-lanes = <1 2>;
			};

			csi_dphy_input1: endpoint@1 {
				reg = <1>;
				remote-endpoint = <&mis5001_out>;
				data-lanes = <1 2>;
			};
		};

		port@1 {
			reg = <1>;
			#address-cells = <1>;
			#size-cells = <0>;

			csi_dphy_output: endpoint@0 {
				reg = <0>;
				remote-endpoint = <&mipi_csi2_input>;
			};
		};
	};
};
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

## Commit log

2026-07-31 Initial public release: PWNCUBE firmware v6, 3D-print case, docs
    Rockchip RV1106 dual-core (Linux + RT-Thread) satellite training platform,
    deliberately vulnerable CCSDS/SPP command stack mirroring FlatSat's
    documented vulnerability catalog.
    [1066mhz_4x128mx16.cfg, 1066mhz_4x256mx16.cfg, 5_SensorBoard_x3.stl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]
2026-07-31 Add Hardware/ (KiCad schematics), Docker build path, and release-asset link fixes
    Add hardware schematics for the three physical boards (main, sensor,
    battery). Document a Docker-based build path for macOS/Linux/Windows in
    getting-started.en.md, alongside the existing native-Ubuntu path. Point
    toolchain/rkbin references at the published v6 Release instead of a bare
    placeholder.
    [0900PC15A0036E--3DModel-STEP-56544.STEP, 1001-001-01000.igs, Batt_Connector.kicad_sch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]
2026-07-31 Document the pressure/altitude overflow bug inline, not just in general terms
    Firmware/README.md's known-limitation note only mentioned altitude and the
    code itself had no comment at all near the affected lines. Add an inline
    comment at telemetry_spp_pack_frame() explaining exactly why pressure
    always overflows and altitude overflows under normal conditions, and
    update the README note to match.
    [command_service.c]
2026-07-31 Fix broken release links and translate remaining Spanish CLI strings
    Firmware/README.md and getting-started.en.md had a wrong relative-path
    depth to the v6 Release. radio_test.c, sensor_test.c, and
    telemetry_test.c had leftover Spanish comments, usage text, and error
    strings, now in English.
